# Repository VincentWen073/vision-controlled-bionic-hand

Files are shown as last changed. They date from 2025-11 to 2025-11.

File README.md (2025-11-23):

# Vision-Controlled Bionic Hand



An open-source project that uses real-time hand tracking to control a bionic hand. This project is built with Python on a Raspberry Pi, utilizing MediaPipe for gesture recognition and serial communication for hardware control.

---

## Demonstration

Project Demonstration GIF

---

## Features

- **Real-time Hand Tracking**: High-performance hand landmark detection using Google's MediaPipe on Raspberry Pi.
- **State Machine Control**: A robust state machine (IDLE, RUNNING, WAITING) manages the application logic for reliability.
- **Dynamic Pose Calibration**: Automatically sets the initial hand pose as the "zero point" for intuitive relative control of the wrist.
- **Smooth Servo Motion**: Implements an EMA (Exponential Moving Average) filter to smooth servo angle commands, resulting in fluid movements.
- **Real-Time Embedded System**: Firmware built on FreeRTOS, featuring a multi-tasking architecture for robust, scalable, and real-time control.
- **Reliable Serial Protocol**: A custom serial protocol with a checksum ensures data integrity between the Raspberry Pi and the microcontroller.
- **Python-based**: The entire high-level logic is written in Python, making it easy to read and extend.

---

## Tech Stack

### Hardware

- **Host Computer**: Raspberry Pi 5
- **Camera**: Raspberry Pi Camera Module v1 (OV5647 Sensor)
- **Robotic Hand Assembly**: 6-DOF Robotic Arm Kit with:
  - 5x LFD-01 Servos (Fingers)
  - 1x LD-1501MG Servo (Wrist Rotation)
- **Servo Driver**: 8-Channel Servo Controller Board
- **Microcontroller**: STM32 NUCLEO F446RE (acts as a bridge between Pi and servo driver)

### Software
- **OS**: Raspberry Pi OS (64-bit recommended for MediaPipe), FreeRTOS (on STM32)
- **Core Frameworks**:
  - **Python 3.9+**
  - **C/C++** (for STM32 Firmware)
  - **OpenCV** for video processing.
  - **MediaPipe** for hand landmark detection.
  - **Picamera2** for modern camera interfacing on Raspberry Pi.
  - **PySerial** for serial communication.
  - **NumPy** for numerical operations.
- **Dev Tools**:
  - **Pytest** for unit testing.
  - **Black** & **Ruff** for code formatting and linting.
  - **GitHub Actions** for Continuous Integration (CI).

---

## Project Structure

```
.
├── .github/workflows/        # CI workflow configuration
├── cad/                      # CAD models of Mechanical Assembly
├── docs/                     # Images and BOM
├── firmware/                 # firmware of driver code on STM32
├── models/                   # MediaPipe model files
├── src/                      # Main source code
│   ├── communication/        # Serial communication module
│   ├── kinematics/           # Kinematics and angle calculation logic
│   ├── visualization/        # OpenCV drawing utilities
│   └── main.py               # Main application entry point
├── tests/                    # Unit tests for the project
├── requirements.txt          # Python dependencies
└── README.md                 # This file
```

---

## Software Architecture

The project's software is split into two main components: a high-level application running on the Raspberry Pi, and a real-time firmware on the STM32 microcontroller.

### High-Level Control (Raspberry Pi)

The main Python application's logic is managed by a robust finite state machine (FSM) to ensure predictable and reliable operation. The state transitions are triggered by user input and hand detection events.

**State Machine Diagram (UML):**

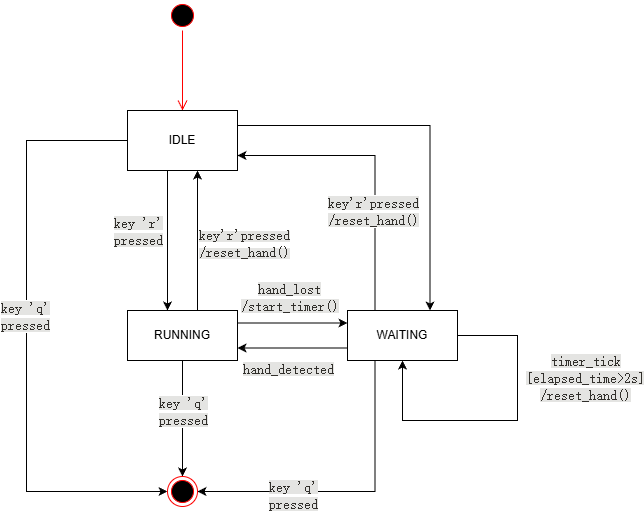
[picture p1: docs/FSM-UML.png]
State Machine Diagram


- **IDLE**: The initial state. The system is waiting for user command and performs no hand tracking.
- **RUNNING**: The active state. The application continuously processes camera frames, calculates servo angles, and sends them to the STM32.
- **WAITING**: A transitional state entered when a hand is lost. If the hand is not re-detected within a timeout, the system resets the robotic hand's pose.

### Real-Time Firmware (STM32)

The embedded firmware is built upon the **FreeRTOS** real-time operating system to handle time-critical tasks reliably.

- **Multi-Tasking Design**: The firmware is architected with two primary tasks:
    1.  A **`uartReceiveTask`** for handling incoming serial data asynchronously.
    2.  A **`servoControlTask`** for updating all 6 servo PWM signals in real-time.
- **Thread-Safe Communication**: A **Message Queue** is used to safely pass angle commands from the receiving task to the control task, preventing data corruption and ensuring smooth motion.

---

## Installation & Usage

### 1. Hardware Setup

**1. Camera Connection:**
   - Connect the **Pi Camera Module** to the Raspberry Pi's CSI port using the ribbon cable.

**2. Power Distribution:**
   - **CRITICAL**: Provide a separate, stable **5V-6V power supply** with sufficient current (e.g., 5A or more) for the **servo driver board's motor power input (VM)**.
   - **DO NOT** power the servos or the driver board from the Raspberry Pi's 5V pin.
   - Ensure a **common ground (`GND`)** is connected between the Raspberry Pi, the STM32, and the servo power supply.

**3. Control Signal Wiring:**
   - The control path is: `Raspberry Pi -> STM32 -> Servo Driver Board -> Servos`.

**Part A: Raspberry Pi to STM32 (Serial Communication)**

This connection is for sending angle commands from the high-level controller (Pi) to the low-level actuator controller (STM32).

| From Raspberry Pi | Pin Name | To STM32 | Pin Name | Purpose |
| :--- | :--- | :--- | :--- | :--- |
| Pin 6 | **GND** | Any **GND** Pin | GND | Common Ground Reference |
| Pin 8 | **TXD** (GPIO 14) | Pin **D2** | RXD | Serial Data to STM32 |
| Pin 10 | **RXD** (GPIO 15) | Pin **D8** | TXD | Serial Data from STM32  |

**Part B: STM32 to 8-Channel Servo Driver Board (PWM Control)**

This connection sends the final PWM signals from the STM32's timers to the servo driver channels.

| From STM32 Pin | To Servo Driver Channel Input | Controlled Servo |
| :--- | :--- | :--- |
| **GND** | **GND** | --- |
| **PA7** | Channel **0** | Wrist Rotation Servo |
| **PA0** | Channel **1** | Thumb Servo |
| **PA1** | Channel **2** | Index Finger Servo |
| **PB10** | Channel **3** | Middle Finger Servo  |
| **PB2** | Channel **4** | Ring Finger Servo |
| **PA6** | Channel **5** | Pinky Finger Servo |

### 2. Mechanical Design & Assembly

The support structure and wrist rotation mechanism for the bionic hand were custom-designed to provide a stable and precise platform for the actuator. The components were modeled in Creo 10.0, focusing on integrating standard machine elements with 3D-printed parts for a robust and reliable assembly.

| Component | Image | Design Highlights |
| :--- | :--- | :--- |
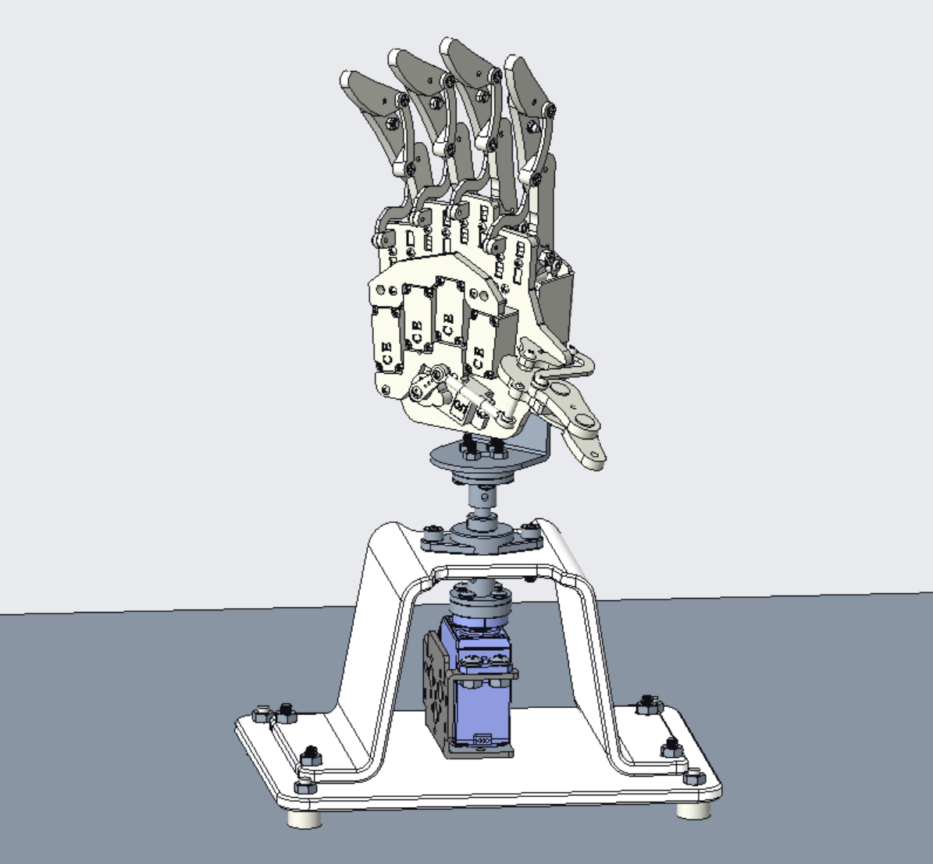
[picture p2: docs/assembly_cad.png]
CAD Rendering of the full assembly
| **Full Mechanical Assembly** |  | • A modular design allowing the hand, wrist, and base to be assembled independently.<br>• Compact layout to maximize the range of motion. |
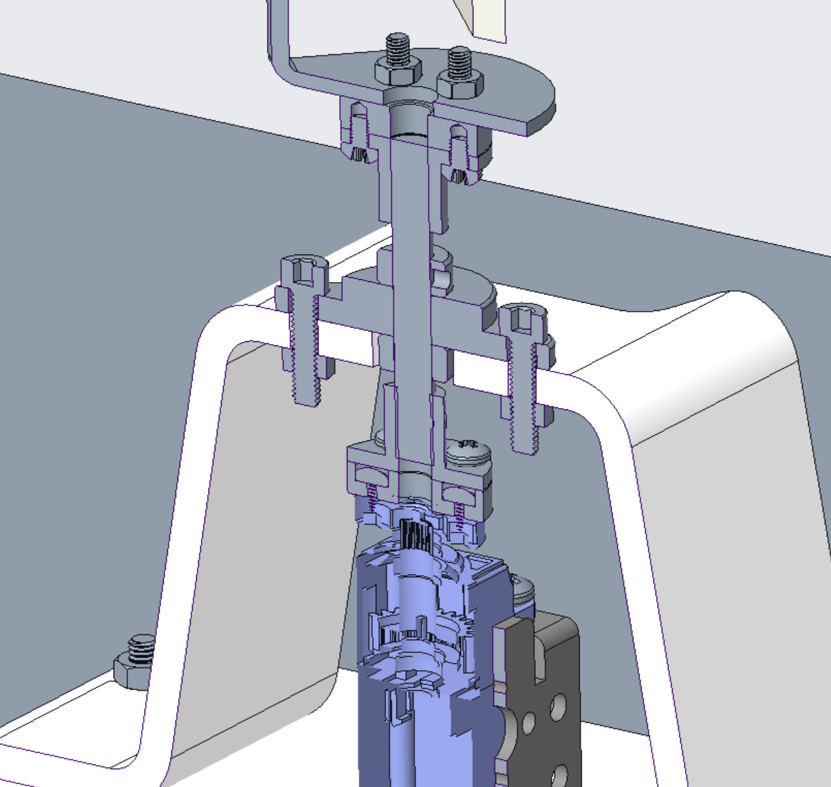
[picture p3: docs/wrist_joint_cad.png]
Wrist Joint Detail
| **Wrist Rotation Joint** |  | • **Pillow block bearing** provides robust radial support and simplifies alignment.<br>• **Shaft collars** are used for precise axial positioning of the main shaft.<br>• Torque is transmitted reliably from the servo via a flange coupling. |
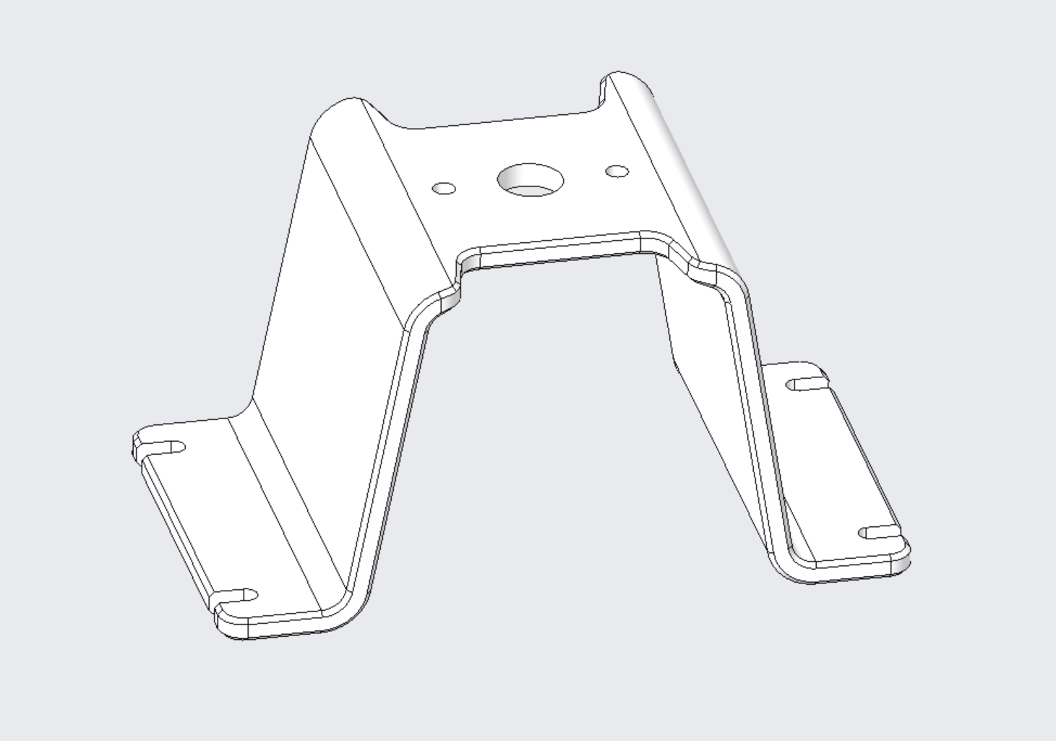
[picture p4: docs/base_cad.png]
Base Detail
| **A-Frame Support Base** |  | • A wide A-frame structure offers **excellent stability** against tipping during operation.<br>• Features an **integrated servo mount** that protects the actuator and optimizes space.<br>• Designed with precise mounting points for the pillow block bearing and fasteners. |

*Note: The hand assembly is a third-party kit, while the base, wrist joint, and all supporting structures were custom-designed for this project.*

### 3. Software Environment

**Clone the repository:**
```bash
git clone https://github.com/VincentWen073/vision-controlled-bionic-hand.git
cd vision-controlled-bionic-hand
```

**Create and activate a virtual environment (recommended):**
```bash
python3 -m venv .venv
source .venv/bin/activate
```

**Install dependencies from `requirements.txt`:**
```bash
pip install -r requirements.txt
```

### 4. Run the Application

Once the setup is complete, run the main script from the project's root directory:

```bash
python -m src.main
```

### Controls
- **`r` key**: Press to toggle the hand recognition state (IDLE <-> RUNNING).
- **`q` key**: Press to quit the application.

---

## Testing

This project uses `pytest` for unit testing the core kinematic functions. To run the tests, execute the following command from the root directory:

```bash
pytest -v
```

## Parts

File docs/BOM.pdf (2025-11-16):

Nr. | Name | Modell | Menge | Gekauft | Anmerkung
001 | Roboterhand | ROBOTERHAND | 1 | J
002 | L-Stütze | L_BRACKET | 1
003 | Adapterplatte für Servohebel | HORN_ADAPTER_PLATE | 2 | J
004 | Flanschkupplung | FLANGE_COUPLING | 2
005 | 6mm*45mm Welle | SHAFT | 1 | J
006 | Stellring+M3 Gewindstift | SHAFT_COLLAR | 2 | J
007 | Flanschlager | KFL06 | 1 | J
008 | Grundplatte | BASE_PLATE | 1 | J | muss angefertigt werden;
009 | Servomotor+Servohobel | LD_1501MG | 1 | J
010 | U-Platte | HAND_PLATE | 1 | J | muss angefertigt werden;
011 | Motorstütze | SERVO_BRACKET | 1 | J
/ | M3*10 Linsensenkkopfschraube | M3_10 | 8 | J
/ | M3 Sechskantmutter | M3_NUTS | 8 | J
/ | M3*5 Linsensenkkopfschraube | M3_5 | 12 | Inkl. | Nicht extra bestellen Im Lieferumfang von Pos. 003/004 enthalten
/ | M4*16 Inbusschraube | M4_16 | 6 | J
/ | M4 Sechskantmutter | M4_NUTS | 10 | J
/ | M4*8 Linsensenkkopfschraube | M4_8 | 4 | Inkl. | Nicht extra bestellen Im Lieferumfang von Pos. 009 enthalten
/ | Gummifüße ADJUSTABLE_FOOT_M4_12_7 4 | | | J

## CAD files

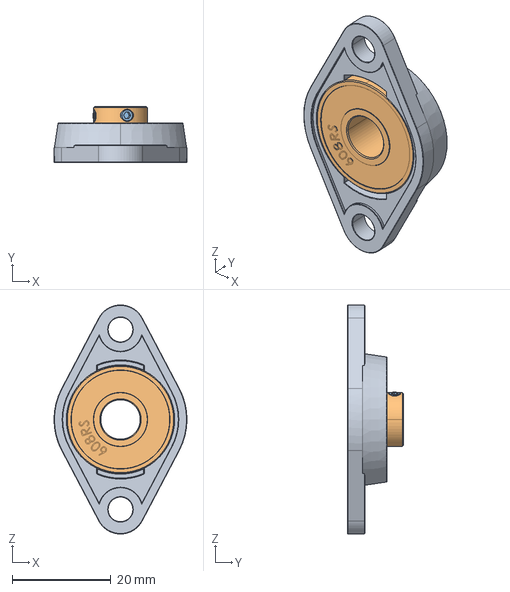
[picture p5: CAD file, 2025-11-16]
cad/Bearing_KFL08.stp
27.0 x 11.4 x 46.5 mm

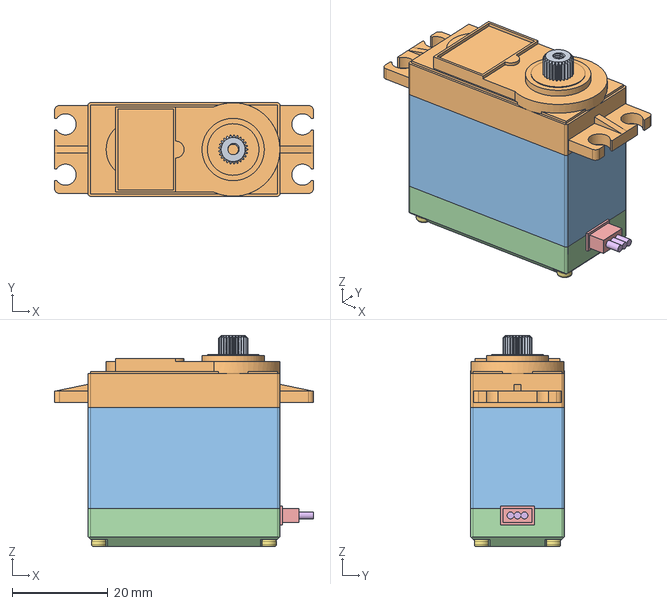
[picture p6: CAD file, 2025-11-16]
cad/mg996r v17.step
54.0 x 19.5 x 44.0 mm

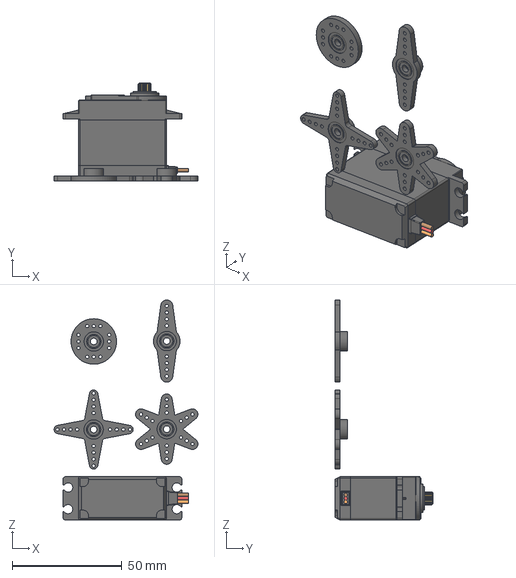
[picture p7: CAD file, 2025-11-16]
cad/Servo Motor MG996R_舵盘.step
65.4 x 44.5 x 100.1 mm

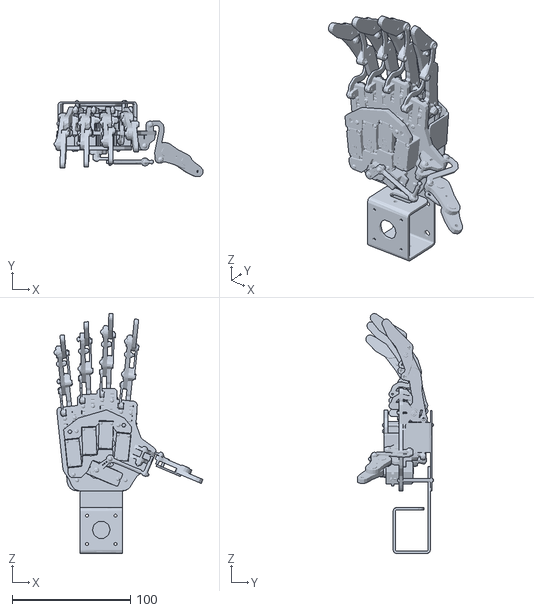
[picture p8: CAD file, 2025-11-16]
cad/roboterarm.stl
126.0 x 64.4 x 203.0

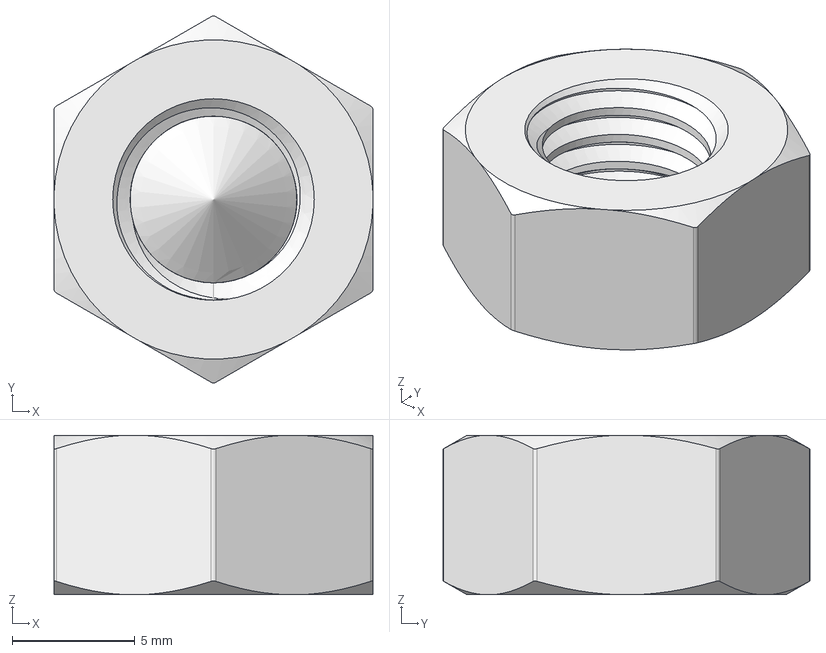
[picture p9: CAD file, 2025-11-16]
cad/M8 Nut v5.step
13.0 x 14.9 x 6.50 mm

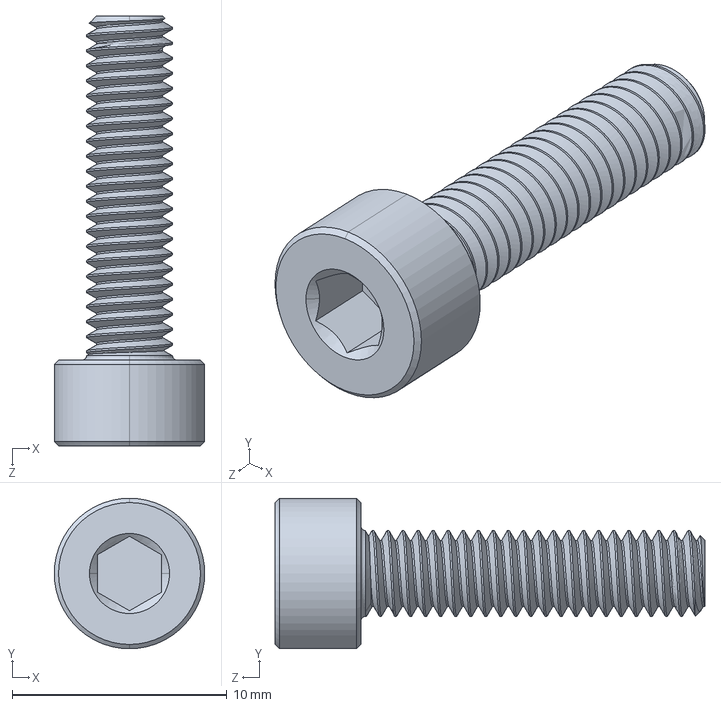
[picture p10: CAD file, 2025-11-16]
cad/91290A154_Alloy Steel Socket Head Screw.STEP
7.00 x 7.00 x 20.0 mm

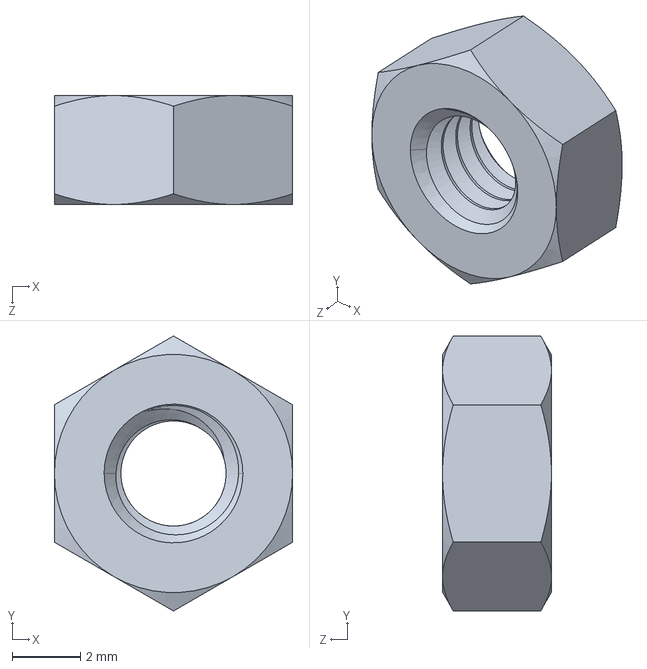
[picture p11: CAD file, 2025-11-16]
cad/90591A255_Zinc-Plated Steel Hex Nut.STEP
7.00 x 8.08 x 3.20 mm

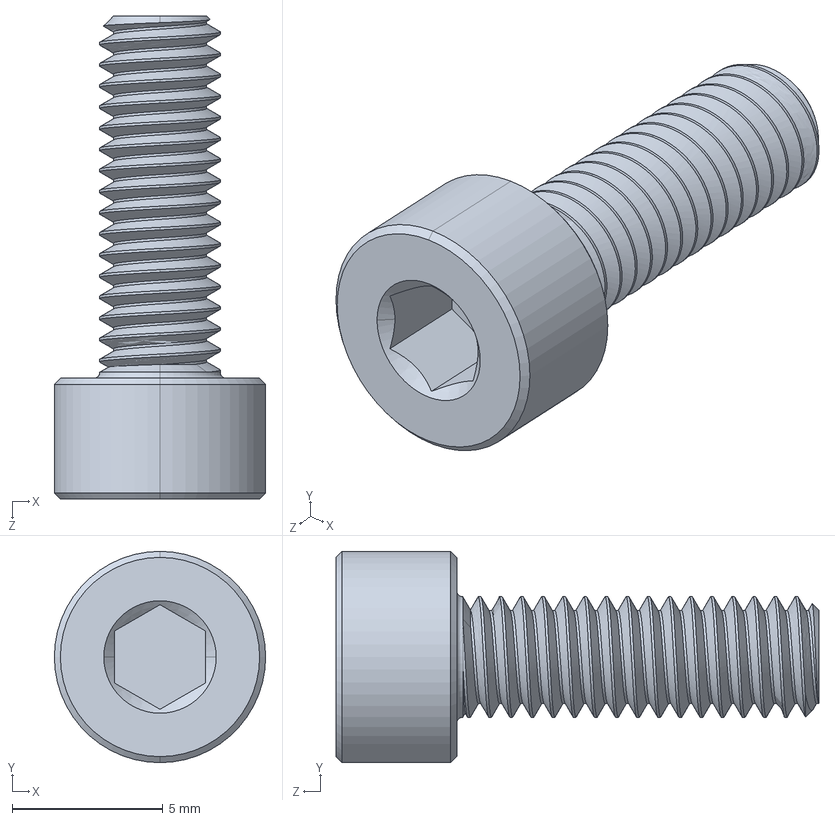
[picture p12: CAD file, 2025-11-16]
cad/91290A148_Alloy Steel Socket Head Screw.STEP
7.00 x 7.00 x 16.0 mm

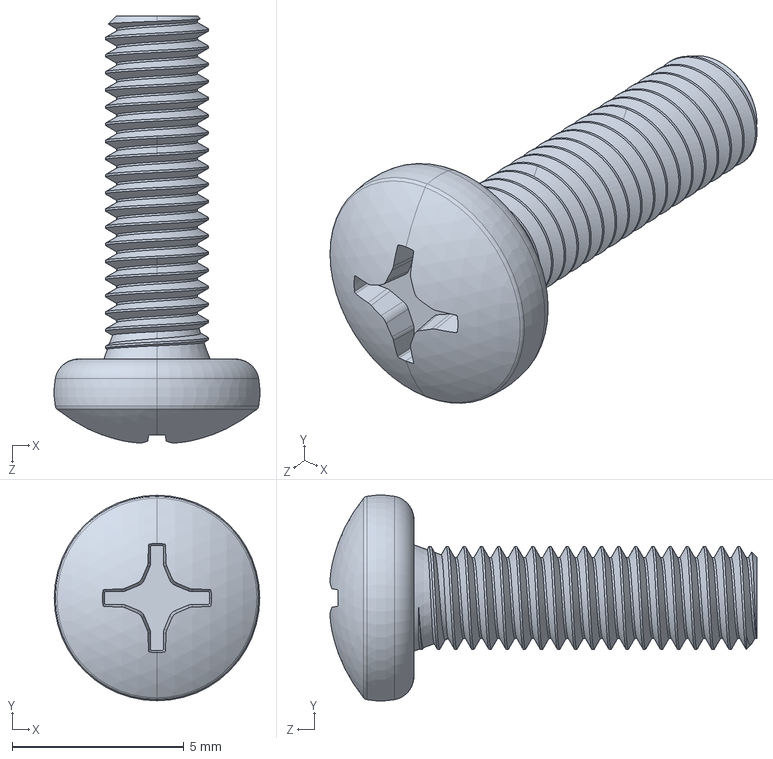
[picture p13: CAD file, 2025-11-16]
cad/92000A120_Passivated 18-8 Stainless Steel Pan Head Phillips Screws.STEP
5.99 x 5.99 x 12.4 mm

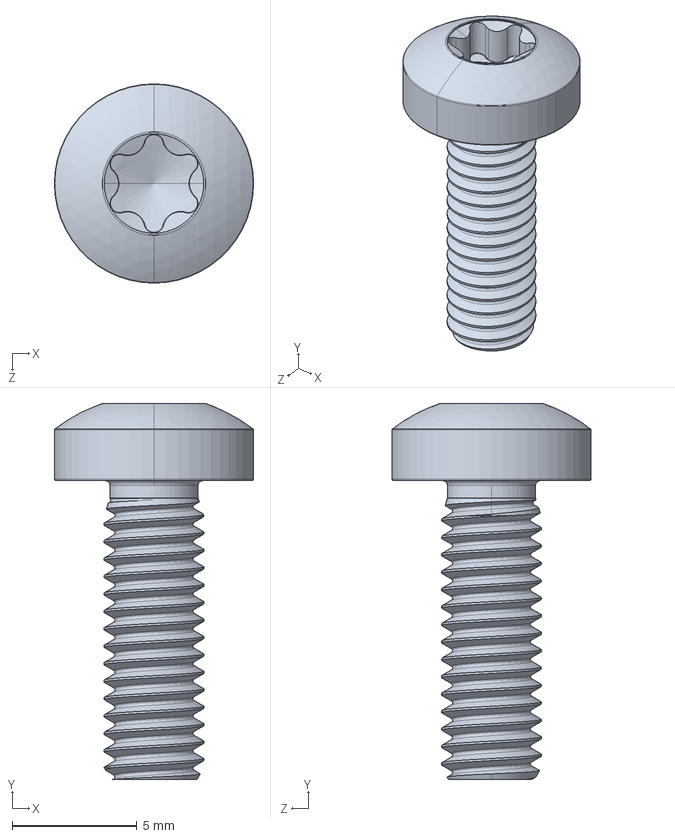
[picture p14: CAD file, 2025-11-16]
cad/STM390400120.step
8.00 x 15.1 x 8.00 mm

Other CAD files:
cad/Servo Motor MG996R.step

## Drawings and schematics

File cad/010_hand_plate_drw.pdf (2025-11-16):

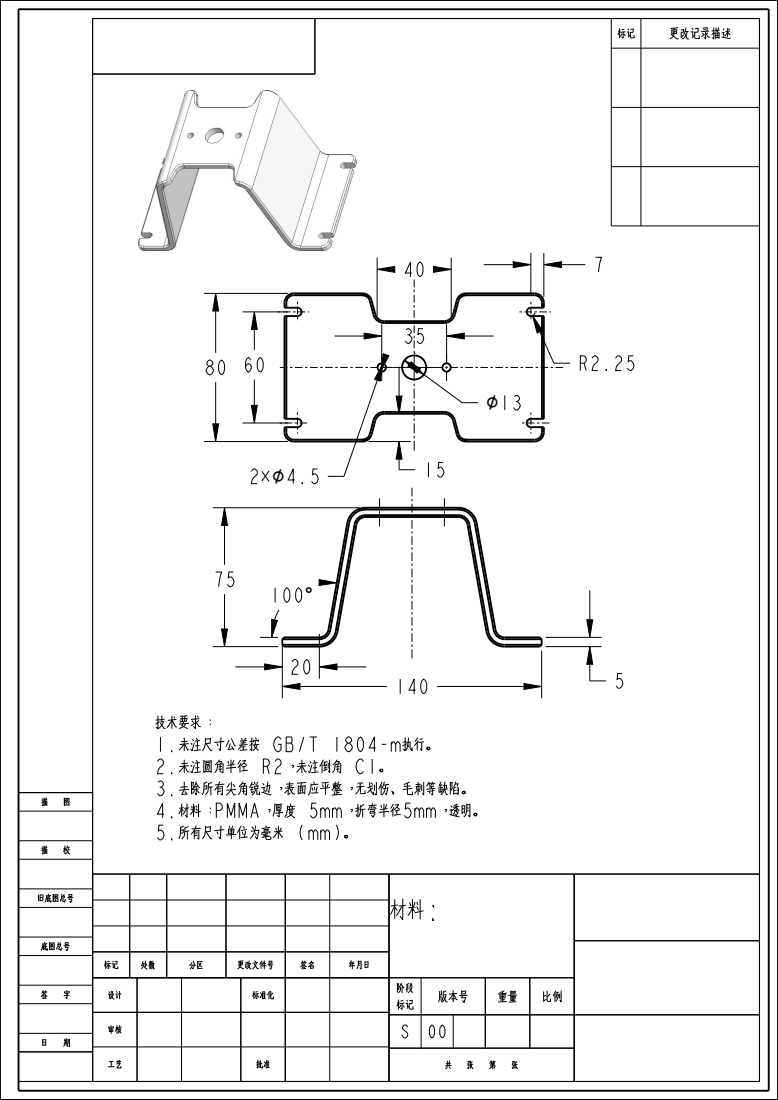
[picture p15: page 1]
旧底图总号; 更改记录描述; 1.未注尺寸公差按; GB/T 1804-m执行。; 4.材料：PMMA，厚度; 5mm，折弯半径5mm，透明。

技术要求：
2.未注圆角半径 R2，未注倒角 C1。
3.去除所有尖角锐边，表面应平整，无划伤、毛刺等缺陷。
5.所有尺寸单位为毫米 (mm)。

底图总号

标记 | 处数 | | 分区 | 更改文件号 | | 签名 | 年月日
设计 | | | 标准化 | | | | 标记 | 版本号 | 重量 | 比例 阶段

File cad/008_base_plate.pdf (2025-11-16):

⌀

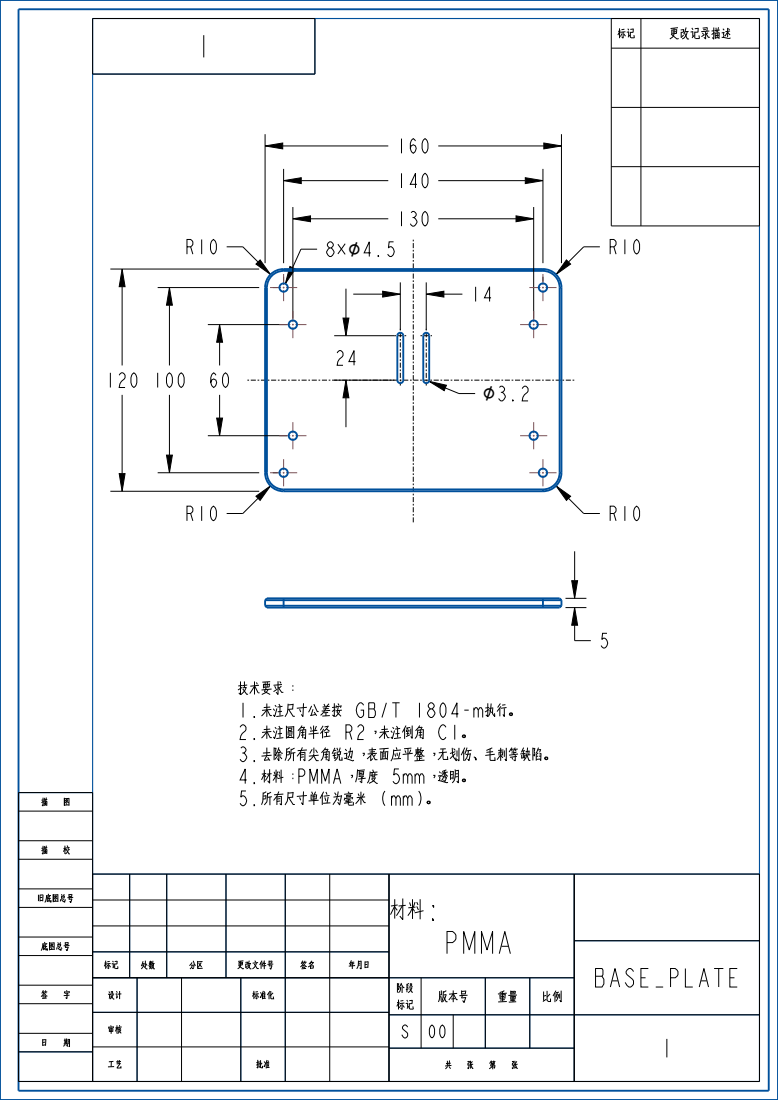
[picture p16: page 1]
旧底图总号; 1.未注尺寸公差按; GB/T 1804-m执行。; 4.材料：PMMA，厚度

技术要求：
2.未注圆角半径 R2，未注倒角 C1。
3.去除所有尖角锐边，表面应平整，无划伤、毛刺等缺陷。
5.所有尺寸单位为毫米 (mm)。

材料: PMMA

底图总号

标记 | 处数 | | 分区 | 更改文件号 | | 签名 | 年月日
设计 | | | 标准化 | | | | 标记 | 版本号 | 重量 | 比例 阶段
审核 | | | | | S | 00 | | | 1

BASE_PLATE

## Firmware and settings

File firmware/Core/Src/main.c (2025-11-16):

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
/* Includes ------------------------------------------------------------------*/
#include "main.h"
#include "cmsis_os.h"

/* USER CODE BEGIN Includes */
#include <stdio.h>
/* USER CODE END Includes */

/* USER CODE BEGIN PD */
#define RX_BUFFER_SIZE 64

/* USER CODE END PD */

TIM_HandleTypeDef htim2;
TIM_HandleTypeDef htim3;

UART_HandleTypeDef huart1;

/* Definitions for uartReceiveTask */
osThreadId_t uartReceiveTaskHandle;
const osThreadAttr_t uartReceiveTask_attributes = {
  .name = "uartReceiveTask",
  .stack_size = 256 * 4,
  .priority = (osPriority_t) osPriorityNormal,
};
/* Definitions for servoControlTas */
osThreadId_t servoControlTasHandle;
const osThreadAttr_t servoControlTas_attributes = {
  .name = "servoControlTas",
  .stack_size = 256 * 4,
  .priority = (osPriority_t) osPriorityHigh,
};
/* Definitions for servoAnglesQueue */
osMessageQueueId_t servoAnglesQueueHandle;
const osMessageQueueAttr_t servoAnglesQueue_attributes = {
  .name = "servoAnglesQueue"
};
/* Definitions for uartRxSemaphore */
osSemaphoreId_t uartRxSemaphoreHandle;
const osSemaphoreAttr_t uartRxSemaphore_attributes = {
  .name = "uartRxSemaphore"
};
/* USER CODE BEGIN PV */
volatile uint8_t motor_enabled = 0;
uint8_t received_byte;
uint8_t rx_buffer[RX_BUFFER_SIZE];
volatile uint8_t data_ready = 0;
/* USER CODE END PV */

void SystemClock_Config(void);
static void MX_GPIO_Init(void);
static void MX_TIM2_Init(void);
static void MX_TIM3_Init(void);
static void MX_USART1_UART_Init(void);
void StartUartReceiveTask(void *argument);
void StartServoControlTask(void *argument);

/* USER CODE BEGIN PFP */
int map_angle_to_pulse(int angle);
/* USER CODE END PFP */

/* USER CODE BEGIN 0 */
int _write(int file, char *ptr, int len)
{
  int DataIdx;
  for (DataIdx = 0; DataIdx < len; DataIdx++)
  {
    ITM_SendChar(*ptr++);
  }
  return len;
}
/* USER CODE END 0 */

/**
  * @brief  The application entry point.
  * @retval int
  */
int main(void)
{

  /* MCU Configuration--------------------------------------------------------*/

  /* Reset of all peripherals, Initializes the Flash interface and the Systick. */
  HAL_Init();

  /* Configure the system clock */
  SystemClock_Config();

  /* Initialize all configured peripherals */
  MX_GPIO_Init();
  MX_TIM2_Init();
  MX_TIM3_Init();
  MX_USART1_UART_Init();
  /* USER CODE BEGIN 2 */
	printf("Starting polling echo test...\n");
	HAL_UART_Receive_IT(&huart1, &received_byte, 1);
	HAL_TIM_PWM_Start(&htim2, TIM_CHANNEL_1);
	HAL_TIM_PWM_Start(&htim2, TIM_CHANNEL_2);
	HAL_TIM_PWM_Start(&htim2, TIM_CHANNEL_3);
	HAL_TIM_PWM_Start(&htim2, TIM_CHANNEL_4);
	HAL_TIM_PWM_Start(&htim3, TIM_CHANNEL_1);
	HAL_TIM_PWM_Start(&htim3, TIM_CHANNEL_2);
  /* USER CODE END 2 */

  /* Init scheduler */
  osKernelInitialize();

  /* USER CODE BEGIN RTOS_MUTEX */
  /* add mutexes, ... */
  /* USER CODE END RTOS_MUTEX */

  /* Create the semaphores(s) */
  /* creation of uartRxSemaphore */
  uartRxSemaphoreHandle = osSemaphoreNew(1, 1, &uartRxSemaphore_attributes);

  /* USER CODE BEGIN RTOS_SEMAPHORES */
  /* add semaphores, ... */
  /* USER CODE END RTOS_SEMAPHORES */

  /* USER CODE BEGIN RTOS_TIMERS */
  /* start timers, add new ones, ... */
  /* USER CODE END RTOS_TIMERS */

  /* Create the queue(s) */
  /* creation of servoAnglesQueue */
  servoAnglesQueueHandle = osMessageQueueNew (1, sizeof(ServoAngles_t), &servoAnglesQueue_attributes);

  /* USER CODE BEGIN RTOS_QUEUES */
  /* add queues, ... */
  /* USER CODE END RTOS_QUEUES */

  /* Create the thread(s) */
  /* creation of uartReceiveTask */
  uartReceiveTaskHandle = osThreadNew(StartUartReceiveTask, NULL, &uartReceiveTask_attributes);

  /* creation of servoControlTas */
  servoControlTasHandle = osThreadNew(StartServoControlTask, NULL, &servoControlTas_attributes);

  /* USER CODE BEGIN RTOS_THREADS */
  /* add threads, ... */
  /* USER CODE END RTOS_THREADS */

  /* USER CODE BEGIN RTOS_EVENTS */
  /* add events, ... */
  /* USER CODE END RTOS_EVENTS */

  /* Start scheduler */
  osKernelStart();

  /* We should never get here as control is now taken by the scheduler */

  /* Infinite loop */
  /* USER CODE BEGIN WHILE */
  while (1)
  {
	  if (data_ready == 1)
	  {
		  data_ready = 0;

		  int angles[6];
		  int checksum_received;

		  int parse_count = sscanf((char*)rx_buffer, "%d,%d,%d,%d,%d,%d,%d",
								   &angles[0], &angles[1], &angles[2],
								   &angles[3], &angles[4], &angles[5],
								   &checksum_received);

		  if (parse_count == 7)
		  {
			  printf("Set of Angles Received: %d,%d,%d,%d,%d,%d,%d\n", angles[0], angles[1], angles[2], angles[3], angles[4], angles[5], checksum_received);
			  int checksum_calculated = 0;
			  for (int i = 0; i < 6; i++) {
				  checksum_calculated ^= angles[i];
			  }

			  if (checksum_calculated == checksum_received)
			  {
				  printf("OK -> Angles: %d,%d,%d,%d,%d,%d\n", angles[0], angles[1], angles[2], angles[3], angles[4], angles[5]);

				  __HAL_TIM_SET_COMPARE(&htim2, TIM_CHANNEL_1, map_angle_to_pulse(angles[0]));
				  __HAL_TIM_SET_COMPARE(&htim2, TIM_CHANNEL_2, map_angle_to_pulse(angles[1]));
				  __HAL_TIM_SET_COMPARE(&htim2, TIM_CHANNEL_3, map_angle_to_pulse(angles[2]));
				  __HAL_TIM_SET_COMPARE(&htim2, TIM_CHANNEL_4, map_angle_to_pulse(angles[3]));
				  __HAL_TIM_SET_COMPARE(&htim3, TIM_CHANNEL_1, map_angle_to_pulse(angles[4]));
				  __HAL_TIM_SET_COMPARE(&htim3, TIM_CHANNEL_2, map_angle_to_pulse(angles[5]));
			  }
			  else {
				   printf("Error: Checksum mismatch!\n");
			  }
		  }
		  else {
			  printf("Error: Format mismatch! Parsed %d values.\n", parse_count);
		  }
	  }
    /* USER CODE END WHILE */

    /* USER CODE BEGIN 3 */
  }
  /* USER CODE END 3 */
}

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
/* USER CODE BEGIN 4 */

int map_angle_to_pulse(int angle)
{
    if (angle < 0) angle = 0;
    if (angle > 180) angle = 180;
    return 500 + (uint32_t)angle * (2500 - 500) / 180;
}


void HAL_UART_RxCpltCallback(UART_HandleTypeDef *huart)
{
    if (huart->Instance == USART1)
    {
    	static uint8_t is_receiving = 0;
    	static uint16_t rx_idx = 0;

		if (received_byte == '<' && is_receiving == 0)
		{

			rx_idx = 0;
			is_receiving = 1;
		}
		else if (is_receiving == 1)
		{
			if (received_byte == '>')
			{
				is_receiving = 0;
				data_ready = 1;
				rx_buffer[rx_idx] = '\0';

				osSemaphoreRelease(uartRxSemaphoreHandle);
			}
			else
			{
				if (rx_idx < RX_BUFFER_SIZE - 1)
				{
					rx_buffer[rx_idx++] = received_byte;
				}
				else
				{
					is_receiving = 0;
				}
			}
		}
		HAL_UART_Receive_IT(huart, &received_byte, 1);
    }
}
/* USER CODE END 4 */

/* USER CODE BEGIN Header_StartUartReceiveTask */
/**
  * @brief  Function implementing the uartReceiveTask thread.
  * @param  argument: Not used
  * @retval None
  */
/* USER CODE END Header_StartUartReceiveTask */
void StartUartReceiveTask(void *argument)
{
  /* USER CODE BEGIN 5 */
  /* Infinite loop */
	  ServoAngles_t servo_cmd;

	  for(;;)
	  {
	    if (osSemaphoreAcquire(uartRxSemaphoreHandle, osWaitForever) == osOK)
	    {
	        int checksum_received;

	        int parse_count = sscanf((char*)rx_buffer, "%d,%d,%d,%d,%d,%d,%d",
	                                 &servo_cmd.angles[0], &servo_cmd.angles[1], &servo_cmd.angles[2],
	                                 &servo_cmd.angles[3], &servo_cmd.angles[4], &servo_cmd.angles[5],
	                                 &checksum_received);

	        if (parse_count == 7) {
	            int checksum_calculated = 0;
	            for (int i = 0; i < 6; i++) {
	                checksum_calculated ^= servo_cmd.angles[i];
	            }

	            if (checksum_calculated == checksum_received) {
	                osMessageQueuePut(servoAnglesQueueHandle, &servo_cmd, 0U, 0U);
	            } else {
	                printf("Error: Checksum mismatch!\n");
	            }
	        } else {
	            printf("Error: Format mismatch! Parsed %d values.\n", parse_count);
	        }
	    }
	  }
  /* USER CODE END 5 */
}

/* USER CODE BEGIN Header_StartServoControlTask */
/**
* @brief Function implementing the servoControlTas thread.
* @param argument: Not used
* @retval None
*/
/* USER CODE END Header_StartServoControlTask */
void StartServoControlTask(void *argument)
{
  /* USER CODE BEGIN StartServoControlTask */
  /* Infinite loop */
  ServoAngles_t received_cmd;
  for(;;)
  {
	  if (osMessageQueueGet(servoAnglesQueueHandle, &received_cmd, NULL, osWaitForever) == osOK)
	      {
	          __HAL_TIM_SET_COMPARE(&htim2, TIM_CHANNEL_1, map_angle_to_pulse(received_cmd.angles[0]));
	          __HAL_TIM_SET_COMPARE(&htim2, TIM_CHANNEL_2, map_angle_to_pulse(received_cmd.angles[1]));
	          __HAL_TIM_SET_COMPARE(&htim2, TIM_CHANNEL_3, map_angle_to_pulse(received_cmd.angles[2]));
	          __HAL_TIM_SET_COMPARE(&htim2, TIM_CHANNEL_4, map_angle_to_pulse(received_cmd.angles[3]));
	          __HAL_TIM_SET_COMPARE(&htim3, TIM_CHANNEL_1, map_angle_to_pulse(received_cmd.angles[4]));
	          __HAL_TIM_SET_COMPARE(&htim3, TIM_CHANNEL_2, map_angle_to_pulse(received_cmd.angles[5]));

	          printf("Servos updated to: %d,%d,%d,%d,%d,%d\n", received_cmd.angles[0],
	                 received_cmd.angles[1], received_cmd.angles[2], received_cmd.angles[3],
	                 received_cmd.angles[4], received_cmd.angles[5]);
	      }
  }
  /* USER CODE END StartServoControlTask */
}

/**
  * @brief  Period elapsed callback in non blocking mode
  * @note   This function is called  when TIM1 interrupt took place, inside
  * HAL_TIM_IRQHandler(). It makes a direct call to HAL_IncTick() to increment
  * a global variable "uwTick" used as application time base.
  * @param  htim : TIM handle
  * @retval None
  */
void HAL_TIM_PeriodElapsedCallback(TIM_HandleTypeDef *htim)
{
  if (htim->Instance == TIM1)
  {
    HAL_IncTick();
  }
}

/**
  * @brief  This function is executed in case of error occurrence.
  * @retval None
  */
void Error_Handler(void)
{
  /* USER CODE BEGIN Error_Handler_Debug */
  /* User can add his own implementation to report the HAL error return state */
  __disable_irq();
  while (1)
  {
  }
  /* USER CODE END Error_Handler_Debug */
}

#ifdef  USE_FULL_ASSERT
/**
  * @brief  Reports the name of the source file and the source line number
  *         where the assert_param error has occurred.
  * @param  file: pointer to the source file name
  * @param  line: assert_param error line source number
  * @retval None
  */
void assert_failed(uint8_t *file, uint32_t line)
{
  /* USER CODE BEGIN 6 */
  /* User can add his own implementation to report the file name and line number,
     ex: printf("Wrong parameters value: file %s on line %d\r\n", file, line) */
  /* USER CODE END 6 */
}
#endif /* USE_FULL_ASSERT */

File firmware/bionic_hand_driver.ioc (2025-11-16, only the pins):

Mcu.UserName=STM32F446RETx
PA0-WKUP.GPIO_Label=SERVOS1_CTRL
PA0-WKUP.Signal=S_TIM2_CH1_ETR
PA1.GPIO_Label=SERVOS2_CTRL
PA1.Signal=S_TIM2_CH2
PA10.Signal=USART1_RX
PA13.GPIO_Label=TMS
PA13.Signal=SYS_JTMS-SWDIO
PA14.GPIO_Label=TCK
PA14.Signal=SYS_JTCK-SWCLK
PA2.GPIO_Label=USART_TX
PA2.Signal=USART2_TX
PA3.GPIO_Label=USART_RX
PA3.Signal=USART2_RX
PA5.GPIO_Label=LD2 [Green Led]
PA5.Signal=GPIO_Output
PA6.GPIO_Label=SERVOS5_CTRL
PA6.Signal=S_TIM3_CH1
PA7.GPIO_Label=LD1501_CTRL
PA7.Signal=S_TIM3_CH2
PA9.Signal=USART1_TX
PB10.GPIO_Label=SERVOS3_CTRL
PB10.Signal=S_TIM2_CH3
PB2.GPIO_Label=SERVOS4_CTRL
PB2.Signal=S_TIM2_CH4
PB3.GPIO_Label=SWO
PB3.Signal=SYS_JTDO-SWO
PC13.GPIO_Label=B1 [Blue PushButton]
PC13.Signal=GPXTI13
PC14-OSC32_IN.Signal=RCC_OSC32_IN
PC15-OSC32_OUT.Signal=RCC_OSC32_OUT
PH0-OSC_IN.Signal=RCC_OSC_IN
PH1-OSC_OUT.Signal=RCC_OSC_OUT

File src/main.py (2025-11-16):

"""
Main application file for the Vision-Controlled Bionic Hand.

This script initializes the camera, MediaPipe hand landmark detection,
serial communication, and runs the main state machine loop for controlling
the bionic hand.

Controls:
    'r': Start/Stop the hand recognition process.
    'q': Quit the application.
"""

import os
import time
from enum import Enum, auto

import cv2 as cv
import mediapipe as mp
import numpy as np
from picamera2 import Picamera2

# Local imports for project-specific modules
from src.visualization.drawing import draw_landmarks_on_image
from src.kinematics import pose_calculator
from src.communication.serial_handler import SerialHandler

# ---Type Aliases and Constants ---
BaseOptions = mp.tasks.BaseOptions
HandLandmarker = mp.tasks.vision.HandLandmarker
HandLandmarkerOptions = mp.tasks.vision.HandLandmarkerOptions
HandLandmarkerResult = mp.tasks.vision.HandLandmarkerResult
VisionRunningMode = mp.tasks.vision.RunningMode


# --- Application State Machine ---
class State(Enum):
    """Defines the operational states of the application."""

    IDLE = auto()
    RUNNING = auto()
    WAITING = auto()


# --- Global Variables for MediaPipe Callback ---
LATEST_RESULT: HandLandmarkerResult = None
INFERENCE_TIME_MS: int = 0


def result_callback(
    result: HandLandmarkerResult, output_image: mp.Image, timestamp_ms: int
):
    """
    Callback function for MediaPipe's async hand detection.

    This function is executed in a separate thread by MediaPipe and is responsible
    for updating the global variables with the latest detection result and
    inference time.

    Args:
        result (HandLandmarkerResult): The hand landmark detection result.
        output_image (mp.Image): The output image with landmarks (not used here).
        timestamp_ms (int): The timestamp of the frame when detection was initiated.
    """
    global LATEST_RESULT, INFERENCE_TIME_MS
    LATEST_RESULT = result
    INFERENCE_TIME_MS = int(time.perf_counter() * 1000) - timestamp_ms


def main():
    """
    Main function to run the hand tracking and control application.
    """
    # --- Configuration ---
    CAMERA_WIDTH, CAMERA_HEIGHT = 640, 480
    SMOOTHING_FACTOR = 0.2
    WAITING_TIMEOUT_S = 2.0
    DEFAULT_SERVO_ANGLES = [0, 180, 180, 180, 180, 90]

    # --- Initialization ---
    print("Initializing camera...")
    picam2 = Picamera2()
    config = picam2.create_video_configuration(
        main={"size": (CAMERA_WIDTH, CAMERA_HEIGHT), "format": "RGB888"}
    )
    picam2.configure(config)
    picam2.start()

    print("Initializing MediaPipe Hand Landmarker...")
    script_dir = os.path.dirname(os.path.abspath(__file__))
    model_asset_path = os.path.join(script_dir, "..", "models", "hand_landmarker.task")
    print(f"Attempting to load model from: {model_asset_path}")
    options = HandLandmarkerOptions(
        num_hands=1,
        min_hand_detection_confidence=0.5,
        base_options=BaseOptions(model_asset_path),
        running_mode=VisionRunningMode.LIVE_STREAM,
        result_callback=result_callback,
    )

    print("Initializing serial communication...")

    try:
        serial_comm = SerialHandler(port="/dev/serial0", baudrate=115200)
    except Exception as e:
        print(f"Failed to connect serial port:{e}. Running in visual-only mode.")
        serial_comm = None

    # --- State and Control Varianbles ---
    current_state = State.IDLE
    waiting_start_time = 0
    is_reference_pose_set = False
    reference_palm_normal = None
    smoothed_angles = np.array(DEFAULT_SERVO_ANGLES, dtype=float)
    fps = 0

    print("Initialization complete. Starting main loop...")
    print("Controls: Press 'r' to start/stop, 'q' to quit.")

    with HandLandmarker.create_from_options(options) as landmarker:
        while True:
            frame_start_time = time.perf_counter()

            # --- Frame Capture and Processing ---
            frame = picam2.capture_array()
            annotated_frame = frame.copy()
            raw_servo_angles = None

            # --- Handle User Input ---
            key = cv.waitKey(40)
            if key == ord("q"):
                print("'Q' Pressed. Exiting program...")
                break

            if key == ord("r"):
                if current_state in [State.RUNNING, State.WAITING]:
                    print("State changed: -> IDLE")
                    current_state = State.IDLE
                    is_reference_pose_set = False
                    if serial_comm:
                        serial_comm.send_angles(DEFAULT_SERVO_ANGLES)
                else:  # current_state is IDLE
                    print("State changed: IDLE -> RUNNING")
                    current_state = State.RUNNING

            # --- State Machine Logic ---
            if current_state != State.IDLE:
                # Perform detection for both RUNNING and WAITING states
                mp_image = mp.Image(image_format=mp.ImageFormat.SRGB, data=frame)
                landmarker.detect_async(mp_image, int(time.perf_counter() * 1000))

            if current_state == State.RUNNING:
                if LATEST_RESULT is not None and LATEST_RESULT.hand_landmarks:
                    landmarks = LATEST_RESULT.hand_landmarks[0]
                    handedness = LATEST_RESULT.handedness[0]
                    if not is_reference_pose_set:
                        print("Capturing palm as reference...")
                        reference_palm_normal = (
                            pose_calculator.calculate_palm_normal_vector(
                                landmarks, handedness[0]
                            )
                        )
                        is_reference_pose_set = True

                    # Calculate and send servo angles
                    annotated_frame = draw_landmarks_on_image(
                        annotated_frame, LATEST_RESULT
                    )
                    raw_servo_angles = pose_calculator.calculate_servo_angles(
                        LATEST_RESULT, reference_palm_normal
                    )
                    print(raw_servo_angles)
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

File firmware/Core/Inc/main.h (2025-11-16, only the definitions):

#define B1_Pin GPIO_PIN_13
#define B1_GPIO_Port GPIOC
#define B1_EXTI_IRQn EXTI15_10_IRQn
#define SERVOS1_CTRL_Pin GPIO_PIN_0
#define SERVOS1_CTRL_GPIO_Port GPIOA
#define SERVOS2_CTRL_Pin GPIO_PIN_1
#define SERVOS2_CTRL_GPIO_Port GPIOA
#define USART_TX_Pin GPIO_PIN_2
#define USART_TX_GPIO_Port GPIOA
#define USART_RX_Pin GPIO_PIN_3
#define USART_RX_GPIO_Port GPIOA
#define LD2_Pin GPIO_PIN_5
#define LD2_GPIO_Port GPIOA
#define SERVOS5_CTRL_Pin GPIO_PIN_6
#define SERVOS5_CTRL_GPIO_Port GPIOA
#define LD1501_CTRL_Pin GPIO_PIN_7
#define LD1501_CTRL_GPIO_Port GPIOA
#define SERVOS4_CTRL_Pin GPIO_PIN_2
#define SERVOS4_CTRL_GPIO_Port GPIOB
#define SERVOS3_CTRL_Pin GPIO_PIN_10
#define SERVOS3_CTRL_GPIO_Port GPIOB
#define TMS_Pin GPIO_PIN_13
#define TMS_GPIO_Port GPIOA
#define TCK_Pin GPIO_PIN_14
#define TCK_GPIO_Port GPIOA
#define SWO_Pin GPIO_PIN_3
#define SWO_GPIO_Port GPIOB

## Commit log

2025-11-16 Initial commit: Complete project with source code, CAD, firmware and docs
    [90591A255_Zinc-Plated Steel Hex Nut.STEP, 91290A148_Alloy Steel Socket Head Screw.STEP, 91290A154_Alloy Steel Socket Head Screw.STEP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]
2025-11-16 fix: Update RTOS firmware and update relevant description in README.md
    [bionic_hand_driver.ioc, main.c, main.h]

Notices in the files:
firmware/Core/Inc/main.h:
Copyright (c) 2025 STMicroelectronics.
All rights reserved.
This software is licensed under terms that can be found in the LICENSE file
